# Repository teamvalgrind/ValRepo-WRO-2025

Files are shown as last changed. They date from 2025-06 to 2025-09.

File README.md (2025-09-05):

# Equipo [Team ValGrind]: WRO 2025

(https://postimg.cc/fSTZzy81)

---

## Índice

1. [Nuestro Equipo](#nuestro-equipo)
    - [Integrantes](#integrantes)
    - [Origenes](#origenes)
    - [Nuestro Objetivo](#nuestro-objetivo)
2. [El Robot](#el-robot)
    - [Apartado Mecanico](#apartado-mecanico)
        - [Impresion 3D](#impresion-3d)
        - [Movilidad](#movilidad)
    - [Apartado Electronico](#apartado-electronico)
        - [Sensores](#sensores)
        - [Conexiones y Circuitos](#conexiones-y-circuitos)
        - [Microcontroladores](#microcontroladores)
    - [Apartado Programatico](#apartado-programatico)
        - [Codigo por Componente](#codigo-por-componente)
4. [Recursos para Hacer el Robot](#recursos-para-hacer-el-robot)

---

## Nuestro Equipo

(https://postimg.cc/rKqWdsNG)

Somos **[Team ValGrind]**, entusiastas de la robótica y la innovación. Representamos a nuestra institución en la fase regional de la **WRO 2025**.

---

### Integrantes

- **Samuel Burgos**  
  17 años, 09/01/2008

  > **Rol:** : **Programador**  
> *Especialista en Python y arquitectura de soluciones complejas. Domina GitHub y PyCharm además de algoritmos complejos*.
> **Fun Fact:**  
> *Su banda favorita es Foo Fighters* 

(https://postimg.cc/BLgVJGSN)

- **Sebastián Salina**  
  17 años, 22/08/2008 

  > **Rol:** **Capitán**
> *Diseña piezas en 3D y además posee la capacidad de imprimir estos mismos al manejar una impresora 3D además de ser el mecánico del equipo*  
> **Fun Fact:**  
> *Una vez imprimió un Pokémon gigante de filamento para Cristobal* 

(https://postimg.cc/GH7xXcKJ)

- **Cristobal Mogollón**
   15 años, 14/07/2010
    
   > **Rol:**  **Programador**  
> *Se encarga principalmente de C++, Arduino IDE, y algunos aspectos de la electrónica.*  
> **Fun Fact:**  
> *Una vez le pidió a Sebastián imprimir un Pokémon gigante de filamento*
 (https://postimg.cc/WdfddD3J)

- **Institución:** [Colegio Salto Ángel](https://www.instagram.com/colegiosaltoangel)
- **Instagram Oficial:** [@team_valgrind](https://instagram.com/team_valgrind)
- **Contáctanos:** [valgrind2025@gmail.com](mailto:valgrind2025@gmail.com)
- **Youtube:**
[Team ValGrind](https://youtube.com/@teamvalgrind?si=ZJbz7CX9eOX75H2U)

---

### Origenes

El nombre de nuestro equipo fue decidido por los tres integrantes a partir de un clásico compilador de C++ llamado de la misma forma, el cual es representado por un logotipo de un dragón hecho con origami. El nombre "ValGrind" también hace referencia a la mitología nórdica debido a las legendarias Valquirias que habitan en este.

 (https://postimg.cc/gryddns4)

> ### ¿Por qué nuestro robot se llama Heimdall?

Este nombre no solo es un guiño a la mitología mencionada, sino que además corresponde al dios conocido como el guardián de las puertas de Asgard y del puente Bifröst, que conecta los Nueve Mundos. Al ser un personaje imponente, consideramos que es un nombre apropiado para representar a nuestro robot en la WRO.

## Nuestro Objetivo

(https://postimg.cc/t1LyR68v)

#### "Diseñar, Construir y Programar"
 Un robot autónomo capaz de superar los desafíos de la WRO 2025, utilizando innovación y trabajo en equipo para lograr un desempeño sobresaliente en la etapa regional y avanzar a la nacional. Para llegar a esto, hemos pasado los últimos meses diseñando, construyendo, armando y programando nuestro más nuevo proyecto "Heimdall"

> [!NOTE]
> La World Robot Olympiad (WRO) es una competencia internacional de robótica educativa que se desarrolla en varias fases, y nuestro equipo lógicamente tiene que comenzar por la fase regional, mediante la cual al ganarla se accede a la Fase Nacional. Cada país organiza su propio torneo clasificatorio, donde equipos de jóvenes compiten en distintas categorías, aplicando conocimientos de robótica y STEAM. Por último, la fase a la cual nuestro equipo quiere llegar es la Final Internacional. Los equipos ganadores de cada país participan en la competencia global, donde enfrentan desafíos más complejos y compiten con representantes de más de 95 países 

(https://postimg.cc/yJrQXB1B)

Aún así, nuestro único objetivo no es solamente ganar, como un equipo unido también tenemos la convicción de poder crear un robot no solo funcional, sino que llene nuestras expectativas; A pesar de ser intangible nuestro deseo de poder culminar nuestro proyecto como un equipo unido y verlo brillar, también es una meta importante para nosotros.

---

## El Robot

(https://postimg.cc/Yv33pbFh)

### Apartado Mecanico

| (https://postimg.cc/62RtZ2t4) | (https://postimg.cc/NL6QfHdW)| 
| :--: | :--: |
| *Frontal* | *Posterior* |
|(https://postimg.cc/B8FnTwCv) | (https://postimg.cc/YhtM4CVj)| 
| *Izquierda* | *Derecha* |
|(https://postimg.cc/YLGgYxjf) |(https://postimg.cc/w1fqYYwM) |
| *Superior* | *Inferior* |

#### Impresion 3D 

Antes de hablar de la movilidad o funcionalidad de nuestro robot, primero hay que explicar nuestros métodos de Diseño e Impresión 3D, los cuales se llevaron a cabo mediante Fusion 360

> [!NOTE]
> Fusion 360 es una plataforma de software de modelado 3D, CAD, CAM, CAE y PCB basada en la nube, destinada al diseño y la fabricación de productos. Nos permite diseñar y crear productos de acuerdo a sus especificaciones particulares, garantizando que cada pieza cumpla con los más exigentes criterios de estética, forma, ajuste y funcionalidad. Además, incorpora un conjunto integral de herramientas avanzadas para el diseño de placas de circuito impreso y componentes electrónicos, lo que facilita la conceptualización y materialización de cualquier idea, incluso las más complejas. Al implementar estas funciones, la plataforma optimiza significativamente tanto el tiempo como los costos asociados, asegurando que el proceso de producción se realice de manera eficiente y que las piezas obtenidas sean de la más alta calidad. Nosotros usamos esta herramienta gráfica y de diseño para realizar los diseños del chasis y las piezas personalizadas de nuestro robot.

(https://postimg.cc/G96s8xCh)

#### Movilidad

Ahora bien, ya habiendo dilucidado como podemos elegir, diseñar y imprimir las piezas de nuestro robot, hay que asegurarnos de que este cuente con las herramientas necesarias para moverse y evadir los obstáculos de la pista.

> [!NOTE]
> Video de Heimdall realizando el Open Challenge
[Video](https://youtu.be/av_kJ_hcNXI?si=83bRdQo1FuN1ajur)

> [!NOTE]
> Video de Heimdall esquivando bloques del Closed Challenge 
[Video](https://youtu.be/y2dTKZ1CmCM?si=7QRf_ff8Sa_BZ0Na)

Nuestro robot emplea un sistema de tracción diferencial, ofreciendo maniobrabilidad precisa para enfrentar los retos del campo de competencia. El sistema de cruces se realiza mediante un servo que ajusta la dirección del robot en intersecciones de forma eficaz. También cabe destacar el hecho de que utilizamos una técnica llamada  Ackermann Positivo para emplear el sistema de movilidad de nuestro vehículo.

(https://postimg.cc/30JGfBkv)

##### El diferencial de los vehículos, como su nombre lo indica, permite que exista una diferencia en la velocidad de giro entre la rueda interna y la rueda externa del vehículo cuando se da una vuelta o se está girando la dirección. No importa si el vehículo es tracción trasera o delantera, la función es la misma.

(https://postimg.cc/G4sWpg3Z)

####  Sistema de Movimiento y Tracción 

Ahondando en lo mencionado anteriormente, Heimdall utiliza lo que normalmente es denominado sistema ackermann positivo, el cual es un sistema derivado del principio de Ackermann, cuyo objetivo es lograr que en curvas la **rueda interior (θᵢ) gire más que la exterior (θₒ)** para minimizar deslizamiento lateral (*scrub*).  

- **Ecuación fundamental**:  
  **cot(θₒ) - cot(θᵢ) = W / L**  
  - *W*: Distancia entre pivotes de dirección (batalla)  
  - *L*: Distancia entre ejes  

### **Implementación Física**
```asciidoc
[Rueda exterior (θₒ)]
  │
  ├─── Brazo de dirección  
  │        \  
[Cuadro]──┤         \  
  │        │          \  
  │        │           ●── Centro teórico (eje trasero)  
  │        │          /  
  │        │         /  
  ├─── Brazo de dirección  
  │  
[Rueda interior (θᵢ > θₒ)]
```

---

##### **Relación de Velocidades en Curva**

```
ωₒ / ωᵢ = (R + W/2) / (R - W/2)
```
- `ωₒ`: Velocidad angular rueda exterior.  
- `ωᵢ`: Velocidad angular rueda interior.  
- `R`: Radio de giro del centro del eje.  

---

##### **Fuerzas en Conflicto**

```mermaid
flowchart LR
    A[Motor] --> B[Diferencial]
    B --> C[Semieje der.\nRueda ext. ωₒ]
    B --> D[Semieje izq.\nRueda int. ωᵢ]
    C --> E[Fuerza de tracción ↑]
    D --> F[Ángulo de giro θᵢ > θₒ]
    E & F --> G[Cuadro]
    G --> H{Deflexión estructural?}
    H -->|Sí| I[Pérdida de Ackermann]
    H -->|No| J[Comportamiento ideal]
```

> [!WARNING]
> De utilizar estos sistemas, recomendamos tener cuidado con los siguientes inconvenientes los cuales aparecieron dentro de nuestras prácticas con la implementación del mencionado sistema:

1. **Paradox Steering**:  
   - *Causa*: La tracción en la rueda interior (baja adherencia) contrarresta el ángulo de giro.  
   - *Solución*: Control electrónico (freno vectorial).  

2. **Fatiga en semiejes**:  
   - *Causa*: Torsión excesiva en juntas homocinéticas debido a θᵢ máximo + par motor.  
   - *Solución*: Semiejes asimétricos con ángulos de trabajo optimizados.  

---

##### Soluciones de Ingeniería
-  **Estrategias Recomendadas**

| **Componente** | **Innovación** | **Beneficio** |
|---|---|---|
| **Cuadro** | Subchasis desmontable con rigidez variable. | Permite ajustes finos en competición. |
| **Diferencial**  | Electrónico con mapas por ángulo de giro. | Regula par según θᵢ/θₒ (ej: Honda SH-AWD). |
| **Dirección** | Brazo de Ackermann ajustable (rótulas roscadas). | Compensa desgaste o cambios de neumáticos. |

--- 

(https://postimg.cc/8syssXPz)

El núcleo de la movilidad de nuestro robot reside en su **subsistema mecánico de transmisión y tracción**, cuidadosamente seleccionado con componentes específicos de alta calidad. Vamos a desglosar cómo cada pieza encaja en este rompecabezas de ingeniería en miniatura, usando la escala **1/18** como referencia clave para tamaño e integración:

1.  **Diferenciales y Ejes de Transmisión (1/18)**

(https://postimg.cc/Cz6T56YC)

---

Los diferenciales se ubican en el eje motriz y permiten que las ruedas izquierda y derecha giren a velocidades diferentes al tomar curvas. Esta característica es fundamental para evitar que el robot patine o experimente esfuerzos innecesarios en giros cerrados, manteniendo así la estabilidad incluso durante maniobras agresivas. Su diseño a escala 1/18 asegura que sean compactos, ligeros y proporcionales al resto del chasis y ruedas del robot de competición.

Por otro lado, los ejes de transmisión conectan directamente la salida de los diferenciales (1/18) a las ruedas motrices. Son responsables de transferir el par motor generado hacia las ruedas, permitiendo el giro de los neumáticos. El diseño a escala 1/18 garantiza la longitud y resistencia necesarias para soportar las fuerzas de torsión y tracción, sin añadir peso excesivo ni desbalancear el robot.

En el caso particular del robot Heimdall, originalmente se consideró una transmisión 4x4. Sin embargo, tras observar las limitaciones en los ángulos de cruce y la maniobrabilidad, se optó por priorizar la movilidad. Por ello, se decidió retirar los ejes de transmisión delanteros, transformando el robot en un sistema de tracción 4x2.

---

#### Diferencias mas importantes entre transmisión 4x4 y 4x2 

| Característica | 4x4 (Tracción en las 4 ruedas) | 4x2 (Tracción en 2 ruedas) |
|---|---|---|
| **Motricidad** | Alta, ideal para terrenos irregulares o cruces complejos. | Moderada, suficiente para la mayoría de maniobras en pista controlada. |
| **Ángulo de cruce** | Limitado por la presencia de ejes delanteros. | Mayor libertad de giro y mejor ángulo de cruce. |
| **Estabilidad en curvas** | Más estable en condiciones extremas. | Buena estabilidad, pero depende más del diseño del chasis y el diferencial. |
| **Peso total** | Mayor, por la cantidad extra de componentes (ejes y diferenciales delanteros). | Menor, lo que contribuye a una mejor relación peso-potencia. |
| **Complejidad mecánica** | Más alta; requiere mayor mantenimiento y ajuste. | Más sencilla, facilita el mantenimiento y reduce fallos mecánicos. |
| **Consumo energético** | Más elevado por la transmisión a cuatro ruedas. | Menor, lo que puede aumentar la autonomía. |
| **Aplicación recomendada** | Terrenos difíciles, obstáculos, máxima tracción. | Pistas controladas, mayor maniobrabilidad y agilidad. |

2. **INJORA 7KG 2065 Digital Micro Servo**

El servo INJS2065 es un Servomotor compacto y de alto rendimiento, ideal para aplicaciones de robótica y modelismo a escala. A la hora de tener en cuenta tanto eficiencia como el manejo del espacio en un sistema embebido como el de un robot, el INJS2065 se destaca por sobre otros modelos. así como también destaca por su rápida velocidad de respuesta, alta precisión en el control de ángulo y considerable torque de retención. lo mencionado ut supra le permite operar eficientemente bajo diversas condiciones de carga. Su amplio rango de voltaje de operación, junto con un motor de núcleo y rodamientos de bolas, asegura durabilidad, flexibilidad y un funcionamiento suave, mientras que su tamaño reducido facilita su integración en diseños que requieren soluciones ligeras y confiables.

(https://postimg.cc/bs6kKQT0)

| :wrench: **Especificaciones del Servo INJS2065** | |
|:---|:---:|
| **Banda muerta** | 2 μs |
| **Posición neutral** | 1500 μs / 330 Hz |
| **Tipo de motor** | Motor de núcleo |
| **Ángulo control remoto** | 90-120° ±2° |
| **Ángulo (500-2500 μs)** | 180° ±2° |
| **Rango de voltaje** | 4.8V - 8.4V |
| **Velocidad de operación (6.0V)** | 0.09 s/60° |
| **Velocidad de operación (8.4V)** | 0.06 s/60° |
| **Torque de retención (6.0V)** | 6.0 kg·cm / 83.3 oz·in |
| **Torque de retención (8.4V)** | 7.0 kg·cm / 97.2 oz·in |
| **Dimensiones** | 23 × 13 × 25.8 mm |
| **Peso** | 20 g |
| **Longitud del cable conector** | JR 300 mm |
| **Rodamientos** | 1BB |
| **Peso con empaque** | 28 g |
| **Tamaño del paquete** | 36 × 23 × 38 mm |

---

| :wrench: **Herramientas requeridas** | |
|:---|:---:|
| 1 × Destornillador hexagonal 1.5 mm | |
| 1 × Destornillador hexagonal 2.0 mm | |

3. ### Motor DC 12V Greartisan zga37irg9i

(https://postimg.cc/LY0yTnX2)

Un Motor de Engranajes DC Greartisan es un tipo de motor eléctrico de corriente continua (DC) que tiene una caja de engranajes (también llamada reductora o caja reductora) integrada directamente en su construcción. La principal funcionalidad de este motor en un sistema robótico radica en su capacidad para ofrecer **alto par a velocidades reducidas**. A diferencia de un motor DC estándar que gira a muy altas RPM con poco par, el motor Greartisan integra una **caja de engranajes** (reductora) directamente en su diseño. Esta caja de engranajes transforma la velocidad de rotación del motor en una fuerza mucho mayor.
 El **eje de salida céntrico de 1.45 pulgadas de diámetro** proporciona una conexión robusta y directa a los sistemas mecánicos del robot, como ruedas, brazos articulados o mecanismos de elevación, asegurando que el par generado se transmita de manera eficiente.

> [!TIP]
>  Evita los movimientos bruscos y difíciles de controlar de los motores de alta velocidad sin reducción.
>     Aunque parezca contradictorio, al operar con una relación de engranajes adecuada, el motor puede trabajar más cerca de su punto de eficiencia óptima para la carga que está manejando, lo que puede resultar en un **menor consumo de energía** en comparación con un motor sin engranajes que lucha por alcanzar el par requerido.

### Especificaciones del Motor

| **Característica** | **Valor** |
|---|---|
| **Voltaje nominal** | 12V |
| **Velocidad** | 10 RPM |
| **Material** | Metal |
| **Par nominal** | 33.1 lbs·cm |
| **Relación de reducción interna** | 1:314 |
| **Corriente nominal** | 0.05A |
| **Tamaño del eje de salida (forma D)** | 6 × 14 mm (0.24" × 0.55") (D × L) |
| **Tamaño de la caja de cambios** | 37 × 31 mm (1.46" × 1.22") (D × L) |
| **Tamaño del motor** | 36.2 × 33.3 mm (1.43" × 1.31") (D × L) |

### Cálculo de la reducción total

Para adaptar la salida del motor a las necesidades del robot, realizamos un cálculo de la reducción total combinando la reducción interna del motor con la de un sistema de engranajes externo. Utilizamos un piñón de ataque estándar (acoplado al eje del motor) y engranajes de 17 y 28 dientes.

La relación de reducción adicional por engranajes se calcula así:
- Si el piñón tiene, por ejemplo, 10 dientes, y el engranaje acoplado tiene 28 dientes, la reducción es 28/10 = 2.8.
- Si se agregan más etapas de engranajes (por ejemplo, usando un engranaje intermedio de 17 dientes), la reducción se multiplica por cada etapa.

La reducción total del sistema es:

```
Reducción total = Reducción interna del motor × (dientes engranaje grande / dientes piñón)
```

Con el Piñón de lego de 36 dientes acomplado a nuestro motor, transmitiendo su fuerza de rotación al Piñon de 16 dientes obtenemos un aumento de 2.11 veces la velocidad original del motor (550 rpm) obteniendo así 1164.7 rpm, siendo reducidos por el Piñón de ataque a una reducción de 1:2.24 
Dando un total de 521 rpm las cuales se transmiten directamente a los ejes de transmisión conectados a las ruedas

### ¿Por qué es importante la reducción?

Dos palabras clave: `Velocidad` y `Torque`. Al aumentar la reducción, la velocidad de salida disminuye, permitiendo un control más preciso del robot, y paralelamente  La reducción aumenta el torque disponible en las ruedas, lo que mejora la capacidad de mover el robot o superar obstáculos.

### Razones para elegir este motor y sistema de reducción

- **Versatilidad y control:** El motor de 12V es estándar y confiable. La reducción interna más la reducción por engranajes externos se adapta perfectamente a las necesidades del robot.
- **Adaptabilidad:** Cambiando los engranajes externos se puede ajustar fácilmente la velocidad y el torque final.
- **Eficiencia y disponibilidad:** Los componentes son fáciles de conseguir y económicos.

---

4.  **Tornillos, Tuercas de Seguridad y Arandelas (M2 y M3)**

(https://postimg.cc/cvHx5n1h)

 ##### Ya sean M2 o M3, son piezas imprescindibles para la mecanica de nuestro robot, debido a la fijacion de piezas pequeñas, estabilización de componentes, y la garantía de seguridad que otorgan con respecto al uso prolongado del robot ya sea en practicas o en la competición.
 ##### Se decidió tomar la decisión de tener tornillos M2 y M3 de forma simultánea para velar por la eficiencia del espacio, para permitir compatibilidad con los componentes más pequeños, y al mismo tiempo para garantizar que los tornillos resistan y permitan estabilidad en el robot.
     
---

### Apartado Electronico

Para el proyecto, decidimos usar;

#### **Baterías**

(https://postimg.cc/K3Nx86D1)

##### Diseñadas para potenciar el rendimiento en competiciones de robótica como la WRO, las baterías Tenergy NiMH de 12 V y 2000 mAh ofrecen dos ventajas críticas: su ausencia de efecto memoria garantiza máxima capacidad en cada uso tras recargas frecuentes (ideal para sesiones de prueba extensas), y su formato compacto (1.969x1.142x2.835 pulgadas) con cables desnudos facilita la integración en espacios reducidos de robots. Con carga rápida ≤1A y larga vida útil, son una solución fiable para  cuando necesitemos usarlas por un tiempo prolongado, ya sea en la propia competición o en pruebas.

> [!TIP]
> Para maximizar rendimiento y seguridad en robots**, cargue siempre estas baterías con un cargador compatible NiMH (como el Tenergy 6V-12V) a ≤1A para evitar sobrecalentamiento y prolongar su vida útil (~500 ciclos). Durante competiciones WRO, monitoree la temperatura (detenga si supera 45°C) y verifique el voltaje post-uso (>10.8V ideal); evite descargas profundas (<0.9V/celda) recargando tras 3-4 sesiones. Almacénelas con 40-60% de carga en ambiente fresco (15-25°C), realice mantenimiento cada 4 semanas si no se usan, y en robots proteja el pack contra golpes con aislante anti-vibración. 

| Característica | Detalle |
|---|---|
| Dimensiones del producto | 2,13 x 2,91 x 1,22 pulgadas |
| ASIN | B077Y9HNTF |
| Número de modelo del producto | 19676 |
| Pilas | 10 12V (Tipo de pila necesaria) |
| Opinión media de los clientes | 4.5 de 5 estrellas (748 opiniones) |
| Clasificación en los más vendidos | nº108,878 en Salud y Hogar |
| | nº250 en Pilas 12 V |
| Descatalogado por el fabricante | No |
| Producto en amazon.com desde | marzo 10, 2018 |
| Voltaje | 12 Voltios |
| Reutilización | Recargable |
| Peso de la batería | 225 Gramos |
| Dimensiones del artículo LxWxH | 2,13 x 2,91 x 1,22 pulgadas |
| Peso del artículo | 255 Gramos |
| Amperaje | 1 Amperios |
| UPC | 844949030014 |
| Fabricante | Tenergy |

### **LM2596**

(https://postimg.cc/RJML9J83)

##### El LM2596 es un regulador step down DC-DC diseñado para transformar tensiones elevadas en niveles adecuados para circuitos electrónicos.  Acepta un rango de entrada entre 3.2 y 40V, Lo cual evidentemente demuestra que es un componente electrónico bastante versátil en lo que al manejo de voltaje respecta, por lo tanto nuestro equipo decidió utilizarlo para poder manejar el voltaje en el circuito del robot de forma idónea.

---

### ** Cuadro Resumen del Datasheet**  
| **Parámetro** | **Valor/Descripción** | **Puntos Relevantes** | |
| --- | --- | --- | --- |
| **Rango de entrada** | 3.2–40 V DC | Compatible con baterías LiPo (7.4V), Pb-ácido (12V), o paneles solares. | |
| **Rango de salida** | 1.25–37 V DC ajustable | Ideal para microcontroladores (5V), sensores (3.3V) o motores (6–12V). | |
| **Corriente máxima** | 3 A (pico), 2 A continuo sin disipador | Suficiente para servomotores, drivers de motores, o sistemas de control. | |
| **Eficiencia** | Hasta 92% , ≈73% @3A | Reduce pérdidas térmicas vs. reguladores lineales, crucial en sesiones largas. | |
| **Frecuencia** | 150 kHz | Permite usar componentes magnéticos pequeños (compacto). | |
| **Temperatura operativa** | -40°C a +85°C | Funciona en entornos extremos (competiciones exteriores). | |
| **Dimensiones** | 45×20×14 mm (estándar) | Fácil integración en espacios reducidos de robots. | |
| **Protecciones** | Limitación de corriente | Previene daños por cortocircuitos en cables o motores. | |
| | | | |

---

### Funcionamiento Técnico 
El LM2596 sigue una topología **buck clásica** con cuatro componentes clave:  
1. **Interruptor (MOSFET)**: Regula el flujo de energía mediante PWM a 150 kHz .  
2. **Bobina (inductor)**: Almacena energía magnética durante el ciclo "ON" y la libera en el "OFF", estabilizando el voltaje .  
3. **Diodo**: Cierra el circuito durante la fase de descarga de la bobina .  
4. **Capacitor**: Filtra rizados (<50 mV ), crucial para microcontroladores sensibles al ruido.  

> [!TIP]
>     - Usar disipador si la corriente supera 1.5A .  
>  - Monitorear temperatura con termómetro IR (>45°C indica riesgo) .  
  - Mantener diferencia mínima de **1.5V entre entrada/salida** (ej: 7.4V entrada → 5V salida) .  
  - Para motores, agregar un **fusible de 2–3A** en serie .    
  - Usar cables AWG 18+ para corrientes >2A .  
  - Evitar loops largos en entrada/salida para reducir rizado.  

---

#### Driver L298N

(https://postimg.cc/Jy29P1P3)

Es un **controlador de motores de doble puente H (dual H-bridge)** encapsulado en un circuito integrado. Su función principal es actuar como un "intermediario de potencia" entre dispositivos de control de baja potencia (como Arduino) y motores de alta potencia (como tu motor DC 12V).

**Es extremadamente útil para nuestro proyecto debido a su:**

1. **Amplificación de corriente:**  
   - Los microcontroladores solo pueden entregar ~20-40mA por pin.  
   - El L298N soporta hasta **2A por canal** (suficiente para motores medianos).  
2. **Control direccional:**  
   - Permite invertir la polaridad del voltaje aplicado al motor para cambiar su giro (adelante/atrás).  
3. **Protección eléctrica:**  
   - Aísla el circuito de control de los picos de voltaje generados por el motor.  
4. **Manejo de alta tensión:**  
   - Soporta motores de 5V a 35V (ideal para tu motor 12V).  

---

#### **Partes clave del módulo L298N:**  
| **Componente** | **Función** |
|---|---|
| **Puertos de salida** (OUT1, OUT2, OUT3, OUT4) | Conectan los motores (2 motores DC o 1 motor paso a paso). |
| **Entradas lógicas** (IN1, IN2, IN3, IN4) | Reciben señales de control desde Arduino (determinan dirección). |
| **Pines de habilitación** (ENA, ENB) | Activan/desactivan los canales (con/sin PWM). |
| **Regulador de 5V** | Provee energía a la lógica (puede alimentar al Arduino si se usa el jumper).|
| **Disipador de calor** | Metálico, previene sobrecalentamiento durante uso prolongado. |
| **Jumpers** | Configuran el modo de operación (ej: habilitación permanente de canales). |

---

#### **¿Cómo controla un motor DC?**  
Usa un circuito **puente H (H-bridge)** interno:  
``` 
   [IN1] --[SW1]---- Motor ----[SW3]-- [IN2]  
               |                   |  
              [SW2]               [SW4]  
```  
- **Giro adelante:**  
  `IN1 = HIGH` (SW1 cerrado) + `IN2 = LOW` (SW4 cerrado) → Corriente fluye: SW1 → Motor → SW4  
- **Giro atrás:**  
  `IN1 = LOW` (SW2 cerrado) + `IN2 = HIGH` (SW3 cerrado) → Corriente fluye: SW3 → Motor → SW2  
- **Frenado:**  
  `IN1 = HIGH` + `IN2 = HIGH` → Cortocircuito en bornes del motor (frena rápidamente).  

---

#### Sensores Ultrasónicos 

(https://postimg.cc/N94J25h9)

##### El robot cuenta con múltiples sensores ultrasónicos (HC-SR04) ubicados estratégicamente para la detección de obstáculos y el cálculo de distancias, permitiendo navegación autónoma y segura. El sensor HC-SR04 es un sensor de distancia de bajo costo, por lo que su uso es muy frecuente en la robótica. Incorpora un par de transductores de ultrasonido que se utilizan de manera conjunta para determinar la distancia del sensor con un objeto colocado frente a este. Un transductor emite una ráfaga de ultrasonido y el otro capta el rebote de dicha onda.

> [!NOTE]
> El tiempo que tarda la onda sonora en ir y regresar a un objeto puede utilizarse para conocer la distancia entre el origen del sonido y el objeto. La interfaz del sensor HC-SR04 y Arduino se logra mediante 2 pines digitales: el pin de disparo (trigger) y el pin de eco (echo). La función de cada uno de estos pines es la siguiente:
- El pin trigger recibe un pulso de habilitación del microcontrolador, mediante el cual se le indica al módulo que comience a realizar la medición de distancia.
- En el pin echo el sensor devuelve al microcontrolador un pulso cuyo ancho es proporcional al tiempo que tarda el sonido en viajar del transductor al obstáculo y luego de vuelta al módulo

- ### ** Cuadro Técnico**  

| **Parámetro** | **HC-SR04** (Estándar) | **US-100** (Avanzado) | **Importancia en Robótica** |
|---|---|---|---|
| **Voltaje operación** | 5 V DC | 2.4–5.5 V DC | Compatibilidad con microcontroladores (3.3V/5V). |
| **Consumo (standby)** | 2 mA | 2 mA | Eficiencia energética en robots autónomos. |
| **Rango de detección** | 2 cm – 400 cm | 2 cm – 450 cm | Evitar colisiones (obstáculos cercanos/lejanos). |
| **Resolución** | 0.3 cm | 0.1 cm | Precisión en navegación de precisión (ej: laberintos). |
| **Ángulo del haz** | 15° | 15° (ajustable a 5° con tubo)| Enfoque en objetivos específicos, reduce falsos positivos. |
| **Frecuencia operativa** | 40 kHz | 42 kHz | Minimiza interferencias con otros sensores acústicos. |
| **Tiempo respuesta** | ≤ 50 ms | ≤ 30 ms | Reacción rápida en robots de alta velocidad (ej: FRC). |
| **Interfaz de salida** | Digital (pulso) | UART/TTL o Digital | Flexibilidad para Arduino, Raspberry Pi, o SBCs. |
| **Precisión** | ±3 mm (2–100 cm), ±5% (>100 cm) | ±2 mm (2–300 cm) | Crítico para mapeo de entornos (SLAM). |
| **Temperatura operativa** | -15°C a +70°C | -25°C a +85°C | Funcionamiento en entornos extremos (exteriores/industriales). |
| **Compensación térmica** | No | Sí (sensor interno) | Mediciones estables con cambios de temperatura. |
| **Dimensiones** | 45×20×15 mm | 41×21×16 mm | Integración en espacios reducidos (mini-robots, drones). |

#### Pixy2

(https://postimg.cc/p9wVTN3Z)

La **Pixy2** es una cámara de visión artificial diseñada para robots que requieren detección rápida y fiable de objetos, colores y códigos de barras. Junto con su software **PixyMon**, forma un ecosistema accesible para principiantes y avanzados, ideal para la detección de los bloques del desafío cerrado. A diferencia de soluciones basadas en cámaras genéricas, Pixy2 procesa imágenes *onboard* con algoritmos optimizados, liberando al microcontrolador principal (Arduino, Raspberry Pi) de tareas intensivas. Su enfoque en **"aprender por demostración"** simplifica el entrenamiento sin necesidad de programación compleja.

---

### ** Cuadro de Datos Técnicos Clave**  
| **Parámetro** | **Pixy2 CMUcam5** | **Puntos Relevantes** | |
| --- | --- | --- | --- |
| **Sensor** | Sony IMX322 (1/4") | Captura 60 FPS en baja luz (torneos indoor/outdoor). | |
| **Resolución** | 1296×976 (RAW), 400×296 (procesada) | Balance óptimo entre detección y velocidad. | |
| **Detección** | Colores (7 firmas), Líneas, Códigos QR, Objetos | Ideal para seguimiento de trayectorias, identificación de objetivos. | |
| **Interfaces** | UART, SPI, I²C, USB, GPIO | Conexión directa a Arduino, Raspberry Pi, PLCs. | |
| **Latencia** | <3 ms (por objeto) | Respuesta en tiempo real para robots ágiles. | |
| **Consumo** | 140 mA @ 5V (máx.) | Alimentable desde puerto USB o fuente de robot. | |
| **Algoritmos integrados** | RANSAC, Vectorización | Detección precisa de líneas incluso con curvas o rupturas. | |
| **Dimensiones/Weight** | 40×40×13 mm / 26 g | Montaje en drones o mini-robots sin afectar movilidad. | |

---

###  Configuración para Entrenamiento de Detección de Colores

(https://postimg.cc/mPBmLMfz) 

1. **Preparación del entorno**:  
   - Iluminar el objeto uniformemente (evite sombras/reflejos).  
   - Usar fondos contrastados (ej: objeto rojo sobre fondo blanco).  

2. **Captura de firmas (signatures)**:  
   - Conecte Pixy2 vía USB y abrir PixyMon → Menú `Action` → `Set signature...`.  
   - Presione el botón físico en Pixy2 o haga clic en `Detect objects` para capturar el color.  
   - Ajuste la sensibilidad con el deslizador `Saturation` (alto para colores vivos, bajo para pasteles).  

3. **Afinación avanzada**:  
   - En `Expert mode`, defina rangos HSV (`Hue`, `Saturation`, `Value`) para reducir falsos positivos.  
   - Use `Color codes` para crear códigos de barras con 2-3 colores (ej: logotipo de competencia WRO).  

4. **Pruebas en tiempo real**:  
   - Active `Frame view` en PixyMon para ver detecciones superpuestas (objetos = rectángulos, líneas = vectores).  
   - Ajuste `Min/max area` para filtrar objetos por tamaño (evitar ruido).   

#### Diagramas de Flujo

##### En este diagrama de flujo se halla una representación gráfica del funcionamiento lógico de nuestra programación, así como de lo que se espera sea el desempeño del robot al inicializar el programa.

##### Desafío Abierto

```mermaid
flowchart LR
    A[Inicio] --> B[Esperar botón de inicio]
    B -- Botón presionado --> C[Iniciar programa]
    C --> D[Contador de giros < 12?]
    D -- No --> E[Avanzar 1.5s y detenerse]
    E --> F[Fin]
    D -- Sí --> G[Leer sensores ultrasónicos]
    G --> H{¿Frontal > 20cm?}
    H -- Sí --> I[Avanzar recto]
    I --> J{¿En tiempo de espera tras giro?}
    J -- Sí --> G
    J -- No --> K{¿Izquierda > 200cm?}
    K -- Sí --> L[Girar izquierda, +1 giro, reset tiempo]
    L --> I
    K -- No --> M{¿Derecha > 200cm?}
    M -- Sí --> N[Girar derecha, +1 giro, reset tiempo]
    N --> I
    M -- No --> I
```

##### Desafío Cerrado

```mermaid
flowchart LR
    A([Inicio]) --> B([void setup])
    B --> C{¿Botón presionado?}
    C -- No --> C
    C -- Sí --> D([programaIniciado = true])
    D --> E([void loop])
    E --> F{¿finalizado?}
    F -- Sí --> G([Termina])
    F -- No --> H([doceGiros])
    H --> I[Lectura sensores]
    I --> J{¿Pixy2 detecta bloques?}
    J -- Sí --> K([goToPosition])
    J -- No --> L{¿Obstáculo al frente?}
    L -- No --> M{¿Espacio libre?}
    M -- Sí --> N[Girar o avanzar]
    M -- No --> O[Parar]
    L -- Sí --> O
    K --> G
    N --> G
    O --> G
```

#### Diagrama de Conexiones 

#### Microcontroladores

##### ESP-32

(https://postimg.cc/f3gkzvyJ)

##### El **ESP32-WROOM** es un módulo todo-en-uno potente y económico basado en el chip ESP32, que integra un **procesador dual-core de hasta 240 MHz**, **Wi-Fi 802.11 b/g/n (2.4 GHz)**, y **Bluetooth (Clásico y BLE)**, junto con **4 MB de memoria flash SPI y 520 KB de RAM** en el mismo encapsulado, además de una antena PCB integrada; ofrece múltiples periféricos (GPIOs, ADC, DAC, UART, SPI, I2C, PWM, etc.), soporta modos de bajo consumo para baterías, y es ideal para proyectos de IoT, domótica, robótica o interfaces, siendo fácil de programar con Arduino IDE, ESP-IDF o MicroPython.
##### Además del microcontrolador, también es necesario tener un buen entorno con las librerías necesarias para compilar y interpretar el código, y eventualmente crear un ecosistema óptimo para nuestro robot. Por esto, hemos decidido utilizar 4 librerías esenciales para lograr nuestro objetivo:

1.  **`Wire.h` (Comunicación I²C):**  
    Esencial para conectar sensores, pantallas (OLED) o memorias (EEPROM) que usen el bus I²C. Con `Wire.begin(SDA, SCL)` configuras los pines, luego usas `Wire.beginTransmission()`, `Wire.write()`, `Wire.read()` y `Wire.endTransmission()` para enviar/recibir datos. A partir de esta librería establecemos comunicación con el ESP-32.

2.  **`NewPing` (Sensor de Distancia Ultrasónico):**
La librería NewPing simplifica y optimiza el uso de sensores ultrasónicos como el HC-SR04. Se inicializa con NewPing sonar(TRIG, ECHO, MAX_DISTANCE), y métodos como sonar.ping_cm() devuelven la distancia en centímetros de forma rápida y precisa. Es ideal para proyectos que requieren detección de proximidad sin contacto, como evitar obstáculos en pistas, prevenir colisiones con paredes internas o externas, sistemas de estacionamiento, y robótica móvil. NewPing maneja automáticamente la generación y recepción de pulsos ultrasónicos, mejora la velocidad de medición y reduce errores gracias a funciones avanzadas como mediciones medianas y control de tiempo máximo de eco.

3.  **`ESP32Servo.h` (Control de Servomotores):**  
    Librería específica para manejar servos en el ESP32, ya que los timers PWM son distintos a Arduino. Con `servo.attach(PIN)` configuras y `servo.write(grados)` posicionas el servo (0°-180°). Crucial para manejar automatismos y conseguir movimiento angular preciso con motores de bajo torque.

4.  **`PixySPI2.h` (Cámara Inteligente Pixy2):**  
    Facilita la comunicación con la cámara Pixy2 (vía SPI) para visión artificial simple. Detecta objetos por color, formas (bloques) o líneas. Usas `pixy.init()` y `pixy.ccc.getBlocks()` para obtener datos. A partir de la pixy, podemos crear código que pueda identificar los bloques verdes, rojos, y el estacionamiento magenta para que actúe acorde y pueda realizar el desafío cerrado.

5 **`SPI.h` (Comunicación SPI en Arduino):**
    La librería SPI.h facilita la comunicación rápida y síncrona entre Arduino (como maestro) y dispositivos periféricos mediante el protocolo Serial Peripheral Interface (SPI). Se inicializa con SPI.begin(), y permite enviar y recibir datos simultáneamente con SPI.transfer(). Es ideal para conectar sensores, memorias, pantallas, y otros módulos que requieren alta velocidad y comunicación full-duplex en distancias cortas. SPI maneja automáticamente las señales de reloj, selección de esclavos (SS), y líneas de datos (MOSI y MISO), simplificando la gestión del bus. Además, ofrece funciones para configurar la velocidad, orden de bits y modo de reloj, adaptándose a distintos dispositivos y aplicaciones industriales o robóticas.

### ¿Por qué Pixy2SPI.h?

 La decisión entre usar **`Pixy2SPI.h`** (comunicación SPI) o **`Pixy2.h`** (comunicación I2C) fue un problema con el que nos encontramos apenas comenzamos a utilizar la PixyCam™. En nuestra experiencia, podemos declarar que el protocolo de comunicación SPI transmite datos de forma más rápida que mediante I²C, y por tanto creemos que vale la pena el elegir Pixy2SPI para poder recibir `signatures`
y datos apenas la pixy los procese

### **1. Rendimiento y Velocidad**  
- **`Pixy2SPI.h` (SPI)**:  
  - **Velocidad máxima**: Hasta **10 Mbps** (dependiendo del microcontrolador).  
  - **Ventaja**: Ideal para aplicaciones que requieren **alta velocidad** (ej: robots en competiciones, procesamiento en tiempo real).  
  - SPI es **full-duplex**, permitiendo transmisión y recepción simultáneas.  

- **`Pixy2.h` (I2C)**:  
  - **Velocidad máxima**: Típicamente **400 kHz** (modo estándar) o **1 MHz** (modo rápido).  
  - **Limitación**: Puede causar cuellos de botella si se transfieren muchos bloques/objetos por fotograma.  

> [!WARNING] 
> ☑️ **Elige SPI si:** Necesitas máxima velocidad (ej: seguimiento de objetos rápidos, FPS alto).
> 
> ☑️**Elige SPI si:** Trabajas en entornos eléctricamente ruidosos (un robot de la WRO)

---

#### Otras razones por las cuales el protocolo SPI nos resultó favorable en testeo y ejecución de la PixyCam en pista:

##### **SPI**:  
  - **Menos susceptible a ruido** gracias a señales de reloj dedicadas y conexiones punto a punto.  
  - Ideal para entornos con motores o fuentes de interferencia (ej: competiciones **FIRST Robotics**).  

##### **I2C**:  
  - Más sensible al ruido debido a su diseño multi-dispositivo en 2 cables.  
  - Puede requerir pull-up resistors adicionales para evitar fallos.  

---

### Apartado Programático

#### Código por Componente

##### Desafío Abierto

El código desarrollado para el robot Heimdall en la categoría Futuros Ingenieros de la WRO 2025 está estructurado para automatizar las acciones del robot en la pista, desde la inicialización hasta la finalización de su recorrido. 

 A continuación, se describe a lujo de detalle y con ejemplos de código cada parte fundamental de este sistema.

Para empezar, se definen los pines y las constantes necesarias para la operación del hardware. Los sensores ultrasónicos se conectan a diferentes pines del ESP32, y se prepara el control del motor y del servo. También se establecen los umbrales de distancia y tiempos que serán usados para la lógica de navegación.

```cpp
#define USTFRONT 13
#define USEFRONT 12
#define USTLEFT 14
#define USELEFT 27
#define USTRIGHT 26
#define USERIGHT 25

#define MAX_DISTANCE 357
#define IN2 17
#define IN1 16
#define PIN_SERVO 2
#define PIN_BOTON 4

const int DISTANCIA_OBSTACULO_FRONTAL = 20;
const int DISTANCIA_OBSTACULO_LATERAL = 200;
const unsigned long DURACION_GIRO_I = 460;
const unsigned long DURACION_GIRO_D = 390;
const unsigned long TIEMPO_ESPERA_GIRO = 1000;
```

El sistema utiliza librerías como `NewPing` para manejar los sensores ultrasónicos y `ESP32Servo` para el control del servo. La inicialización de estos dispositivos es esencial para que el robot tenga control de su entorno y de su propio movimiento:

```cpp
#include <Wire.h>
#include <NewPing.h>
#include <ESP32Servo.h>

NewPing USFRONT(USTFRONT, USEFRONT, MAX_DISTANCE);
NewPing USLEFT(USTLEFT, USELEFT, MAX_DISTANCE);
NewPing USRIGHT(USTRIGHT, USERIGHT, MAX_DISTANCE);

Servo myservo;
```

Las variables de control permiten al robot llevar registro de su estado, los giros realizados y el tiempo entre cada giro, para evitar movimientos no deseados o repetitivos. Estas variables se usan a lo largo del flujo principal del programa.

```cpp
bool programaIniciado = false;
bool finalizado = false;

unsigned long tiempoUltimoGiro = 0;
int contadorGiros = 0;
```

La función `setup()` es la encargada de preparar todo el hardware. Aquí se asocia el servo, se configura la comunicación serial para mensajes de depuración y se definen los pines como entradas o salidas según su función. El servo se centra y todo el sistema espera la interacción del usuario antes de iniciar la lógica automática.

```cpp
void setup() {
  myservo.attach(PIN_SERVO);
  Serial.begin(115200);

  pinMode(PIN_BOTON, INPUT_PULLUP);
  pinMode(IN1, OUTPUT);
  pinMode(IN2, OUTPUT);

  digitalWrite(IN1, LOW);
  digitalWrite(IN2, LOW);
  myservo.write(99);  // Servo centrado
  delay(3000);

  Serial.println("Esperando pulsar botón para iniciar...");
}
```

El ciclo principal del programa se encuentra en `loop()`, donde el robot permanece a la espera de que el usuario pulse el botón de inicio. Una vez detectada la pulsación, el programa entra en la rutina de navegación y ya no responde a más pulsaciones hasta que termina la secuencia de giros.

```cpp
void loop() {
  if (!programaIniciado) {
    if (digitalRead(PIN_BOTON) == LOW) {
      programaIniciado = true;
      Serial.println("Botón presionado, iniciando programa...");
      delay(500);  // debounce
    }
  } else if (!finalizado) {
    docegiros();
  }
}
```

La función `docegiros()` es la función principal dentro del código. Aquí se leen los sensores ultrasónicos, se decide si avanzar o girar, y se lleva el conteo de los giros. Un ejemplo de lectura de los sensores y validación de las lecturas sería:

```cpp
void docegiros() {
  unsigned long ahora = millis();

  int frontal = USFRONT.ping_cm();
  int izquierda = USLEFT.ping_cm();
  int derecha = USRIGHT.ping_cm();

  if (frontal == 357) frontal = -1;
  if (izquierda == 357) izquierda = -1;
  if (derecha == 357) derecha = -1;

  Serial.print("Distancias (cm) - Frontal: ");
  Serial.print(frontal);
  Serial.print(" | Izquierda: ");
  Serial.print(izquierda);
  Serial.print(" | Derecha: ");
  Serial.println(derecha);

  if (contadorGiros >= 12) {
    if (!finalizado) {
      Serial.println("Se alcanzaron 12 giros, avanzando 1 segundo más y deteniéndose.");
      Adelante();
      delay(700);
      Parar();
      finalizado = true;
    }
    return;
  }

  if (frontal != -1 && frontal > DISTANCIA_OBSTACULO_FRONTAL) {
    Adelante();
  }

  if (ahora - tiempoUltimoGiro < TIEMPO_ESPERA_GIRO) {
    Serial.println("Avanzando recto después del giro, sin girar");
  } else {
    if (izquierda != -1 && izquierda > DISTANCIA_OBSTACULO_LATERAL) {
      Serial.println("Girando a la izquierda por más de 190 cm libres");
      Izquierda();
      contadorGiros++;
      tiempoUltimoGiro = millis();
      Adelante();
    } else if (derecha != -1 && derecha > DISTANCIA_OBSTACULO_LATERAL) {
      Serial.println("Girando a la derecha por más de 190 cm libres");
      Derecha();
      contadorGiros++;
      tiempoUltimoGiro = millis();
      Adelante();
    }
  }
}
```

Las funciones auxiliares de movimiento encapsulan la lógica para avanzar, parar y girar. Por ejemplo, para avanzar el motor se activa y para parar se desactiva:

```cpp
void Adelante() {
  digitalWrite(IN1, HIGH);
  Serial.println("Motor en marcha hacia adelante");
}

void Parar() {
  digitalWrite(IN1, LOW);
  Serial.println("Motor detenido");
}
```

Los giros a izquierda y derecha combinan el movimiento del motor con el ajuste del servo, utilizando temporizadores para asegurar que el giro tenga la duración adecuada. Así, el robot puede girar de manera controlada y precisa antes de volver a avanzar.

```cpp
void Izquierda() {
  digitalWrite(IN1, HIGH);
  myservo.write(150);
  unsigned long inicio = millis();
  while (millis() - inicio < DURACION_GIRO_I) {
    delay(10);
  }
  myservo.write(97);  // Centrar servo
  digitalWrite(IN1, LOW);
  Serial.println("Giro izquierda completado");
}

void Derecha() {
  digitalWrite(IN1, HIGH);
  myservo.write(30);
  unsigned long inicio = millis();
  while (millis() - inicio < DURACION_GIRO_D) {
    delay(10);
  }
  myservo.write(100);  // Centrar servo
  digitalWrite(IN1, LOW);
  Serial.println("Giro derecha completado");
}
```

En resumen, este sistema permite que el robot navegue autónomamente por la pista, tome decisiones en tiempo real basadas en la información de los sensores, y complete el reto de realizar 12 giros antes de detenerse automáticamente. Se decidió usar funciones auxiliares para poder crear un "ecosistema" de herramientas que nos permitieran manejar el comportamiento y preferencias del robot de tal forma que su desempeño en la pista sea fácilmente optimizable. Esto también ocurre dentro del Desafío Cerrado

##### Desafío Cerrado

La lógica de programación del Desafío Cerrado se basa principalmente en la integración y procesamiento de la información proporcionada por la cámara Pixy2, junto con la interpretación de datos de sensores ultrasónicos y la reacción coordinada de los motores y el servo de dirección. El objetivo es que el robot detecte colores específicos en la pista (por ejemplo, bloques verdes o rojos), interprete su posición y tome decisiones inteligentes y adaptativas para sortear obstáculos o ejecutar maniobras según el contexto de la competencia.

Para lograr esto, el sistema parte de una inicialización robusta de todos los periféricos. Se definen los pines y canales de control para el motor (mediante un puente H y PWM), el servo de dirección, el botón de inicio y los sensores ultrasónicos distribuidos en el frente y laterales del robot. También se configura la cámara Pixy2 para operar en modo de detección de componentes de color, lo que facilita la identificación rápida y eficiente de objetos de interés en la pista. Un fragmento típico de esta inicialización se ve así:

```cpp
#include <Wire.h>
#include <ESP32Servo.h>
#include <SPI.h>
#include <Pixy2SPI_SS.h>
#include <NewPing.h>

#define IN1 16
#define IN2 17
#define MOTOR_PWM_CHANNEL 6
#define MOTOR_PWM_PIN IN1
#define PIN_SERVO 2
#define PIN_BOTON 4

#define USTLEFT 14
#define USELEFT 27
#define USTRIGHT 26
#define USERIGHT 25
#define USTFRONT 13
#define USEFRONT 12

Pixy2SPI_SS pixy;
Servo myservo;

NewPing sensorFront(USTFRONT, USEFRONT, 357);
NewPing sensorIzq(USTLEFT, USELEFT, 357);
NewPing sensorDer(USTRIGHT, USERIGHT, 357);
```

Desde el arranque, el robot permanece en estado de espera hasta que el usuario presiona el botón de inicio. En ese momento, se inicia la secuencia de centrado y avance, y el robot comienza a monitorear constantemente la información visual y de proximidad. Mediante la función `loop`, el robot evalúa el estado general y ejecuta acciones basadas en una máquina de estados que contempla escenarios como avanzar, girar, retroceder ante obstáculos, realizar correcciones de trayectoria y ejecutar maniobras especiales ante la detección de colores específicos:

```cpp
void loop() {
  if (!programaIniciado) {
    if (digitalRead(PIN_BOTON) == LOW) {
      programaIniciado = true;
      Serial.println("Programa iniciado.");
      delay(500);
      estadoActual = CENTRANDO_INICIAL;
      tiempoInicio = millis();
    }
    return;
  }

  pixy.ccc.getBlocks();

  int front = leerSensorFiltrado(sensorFront);
  int left = leerSensorFiltrado(sensorIzq);
  int right = leerSensorFiltrado(sensorDer);

  switch (estadoActual) {
    case ESPERANDO:
      break;
    case CENTRANDO_INICIAL:
      estadoActual = AVANZANDO;
      break;
    case AVANZANDO:
      // ... lógica de avance y detección de obstáculos
      break;
    // ... otros estados
  }
}
```

Parte esencial de la lógica es el procesamiento de los bloques detectados por la Pixy2. En cada ciclo, se consulta la cantidad de bloques detectados. Si hay bloques, se leen sus coordenadas y su firma (color). Esta información se utiliza para determinar acciones específicas. Por ejemplo, si se detecta un bloque verde (firma 1) y este está en una posición determinada del encuadre de la cámara, el robot puede decidir avanzar recto o realizar un giro suave a la izquierda. En caso contrario, si no hay bloques o la posición no coincide con los umbrales establecidos, el robot puede corregir su trayectoria o seguir avanzando recto, manteniendo siempre la lógica adaptativa.

```cpp
pixy.ccc.getBlocks();

if (pixy.ccc.numBlocks) {
  int y = pixy.ccc.blocks[0].m_y;
  int x = pixy.ccc.blocks[0].m_x;
  uint8_t sig = pixy.ccc.blocks[0].m_signature;

  Serial.print("Firma detectada: ");
  Serial.println(sig);
  Serial.print("Posición X: ");
  Serial.print(x);
  Serial.print(" Y: ");
  Serial.println(y);

  if (sig == 1 && y > UMBRAL_Y) {
    if (!girando) {
      girando = true;
      tiempoInicioGiro = millis();

      if (x > UMBRAL_IZQUIERDA) {
        Serial.println("Bloque verde a la derecha: Avanzar recto");
        Adelante();
        giroIzqActivo = false;
      } else {
        Serial.println("Bloque verde a la izquierda: Giro suave izquierda");
        giroIzquierdaSuave();
        giroIzqActivo = true;
      }
    } else {
      Adelante();
    }
  } else {
    if (girando && millis() - tiempoInicioGiro >= TIEMPO_GIRO_SUAVE) {
      if (giroIzqActivo) {
        Serial.println("Corrección giro derecha para enderezar");
        correccionDerecha();
      }
      girando = false;
    } else {
      Adelante();
    }
  }
} else {
  if (girando && millis() - tiempoInicioGiro >= TIEMPO_GIRO_SUAVE) {
    if (giroIzqActivo) {
      Serial.println("Corrección giro derecha para enderezar");
      correccionDerecha();
    }
    girando = false;
  } else {
    Adelante();
  }
}
```

Las funciones de control de movimiento se encargan de traducir las decisiones de la lógica central en acciones físicas del robot. Por ejemplo, la función `Adelante` activa el motor para avanzar recto y centra el servo; `giroIzquierdaSuave` ajusta el servo para un giro controlado a la izquierda; y `correccionDerecha` realiza una corrección puntual al servo para volver a la trayectoria central tras un giro.

```cpp
void Adelante() {
  digitalWrite(IN1, HIGH);
  digitalWrite(IN2, LOW);
  myservo.write(97);
  Serial.println("Avanzando recto");
}

void giroIzquierdaSuave() {
  digitalWrite(IN1, HIGH);
  digitalWrite(IN2, LOW);
  myservo.write(140);
  Serial.println("Girando suavemente a la izquierda");
}

void correccionDerecha() {
  digitalWrite(IN1, HIGH);
  digitalWrite(IN2, LOW);
  myservo.write(30);
  delay(TIEMPO_CORRECCION);
  myservo.write(97);
  Serial.println("Corrección giro derecha completada");
}
```

La integración de los sensores ultrasónicos permite al robot complementar la información visual de la Pixy2 con la percepción de distancias a los obstáculos. Así, el robot no solo reacciona a los colores detectados, sino que también puede evitar colisiones y ajustar su trayectoria para sortear paredes o bloques inesperados. Para este fin, la lectura de los sensores se filtra y se promedia para reducir el efecto del ruido y obtener medidas más confiables:

```cpp
int leerSensorFiltrado(NewPing& sensor) {
  int lecturas[LECTURAS_SENSOR];
  for (int i = 0; i < LECTURAS_SENSOR; i++) {
    lecturas[i] = sensor.ping_cm();
    delay(10);
  }
  // Ordenar lecturas (bubble sort simple)
  for (int i = 0; i < LECTURAS_SENSOR - 1; i++) {
    for (int j = 0; j < LECTURAS_SENSOR - i - 1; j++) {
      if (lecturas[j] > lecturas[j + 1]) {
        int temp = lecturas[j];
        lecturas[j] = lecturas[j + 1];
        lecturas[j + 1] = temp;
      }
    }
  }
  // Usar la mediana
  return lecturas[LECTURAS_SENSOR / 2];
}
```

El uso de una **máquina de estados** permite que el robot maneje situaciones complejas, como la secuencia de retroceder y girar en caso de encontrar un obstáculo frontal, o la lógica de doble giro y corrección tras superar cruces especiales. Cada estado define no solo qué hacer en cada momento, sino también cuándo y cómo pasar al siguiente estado, dependiendo de los tiempos, las lecturas de sensores y las señales de la Pixy2. Por ejemplo, tras detectar un obstáculo, el robot puede retroceder, ejecutar un giro, y luego avanzar sin corrección durante un tiempo predefinido antes de volver al modo de navegación normal.

La función encargada de decidir la reacción ante un bloque detectado por la Pixy2 evalúa tanto el color como la posición X para determinar si se debe iniciar un giro parcial o completo, y en qué dirección:

```cpp
void detectarBloque(uint8_t color, int x) {
  if (color == 1) { // Verde
    if (x >= UMBRAL_IZQUIERDA && x <= UMBRAL_DERECHA) {
      iniciarGiroParcial(1);
    } else if (x < UMBRAL_IZQUIERDA) {
      iniciarGiro(1);
    }
  } else if (color == 2) { // Rojo
    if (x >= UMBRAL_IZQUIERDA && x <= UMBRAL_DERECHA) {
      iniciarGiroParcial(2);
    } else if (x > UMBRAL_DERECHA) {
      iniciarGiro(2);
    }
  }
}
```

---

Dentro de `Desafio-abierto.ino` y `Desafio-cerrado.ino` está el resto de funciones descritas, y la lógica de programación mediante la cual el robot completa el desafío abierto y cerrado.

#### Compiladores y Comunicacion

- **Lenguaje principal:** C++ (Arduino IDE)
- **Compilador:** [Arduino IDE](https://www.arduino.cc/en/software- **Comunicación entre módulos:** Bus I2C

---

## Recursos para Hacer el Robot

| Producto | Cantidad | Precio | Tipo | Link |
|---|---|---|---|---|
| Tenergy TB-6AB Balance Charger Discharger 1S-6S | 1 | 39.99$ | Electrónico | [Enlace](https://a.co/d/g4CIJV4) |
| Tenergy 2 Pack 12V 2000mAh Battery Packs RC | 1 | 39.99$ | Electrónico | [Enlace](https://a.co/d/7CcqbaV) |
| 1683 Pcs M3 Screw Assortment | 2 | 16.99$ | Herramienta | [Enlace](https://a.co/d/hlXXkAq) |
| Vertical Heat Press Machine-Heat Set Insert Tool | 1 | 56.99$ | Herramienta | [Enlace](https://a.co/d/0QgemD) |
| FNIRSI HS-02A 100W Portable Corded Soldering Iron Kit | 1 | 95.99$ | Herramienta | [Enlace](https://a.co/d/7zn4xyp) |
| Kit de amortiguación y dirección escala 1/24 | 1 | 33$ | Herramienta | [Enlace](https://a.co/d/1lKXhpT) |
| Caja de engranajes diferenciales escala 1/28 | 1 | 14$ | Herramienta | [Enlace](https://a.co/d/7Y6jsIC) |
| Diferenciales y ejes de transmisión 1/28 | 1 | 27$ | Mecánico | [Enlace](https://a.co/d/1KSovrP) |
| Conectores XT30 | 1 | 13$ | Electrónico | [Enlace](https://a.co/d/6dxQdtF) |
| Conectores XT90 | 1 | 23$ | Electrónico | [Enlace](https://a.co/d/9AgJER6) |
| Servomotores Injora 2065 7kg (3 Pcs) | 1 | 48$ | Mecánico | [Enlace](https://a.co/d/hfQbhOa) |
| Brazo de Servomotor Injora 25T | 1 | 9$ | Mecánico | [Enlace](https://a.co/d/9PtCohQ) |
| ESP32 | 1 | 10$ | Electrónico | [Enlace](https://www.amazon.com/ESP32-WROOM-32-Development-ESP-32S-Bluetooth-Arduino/dp/B084KWNMM4) |
| Step Down LM2596 | 1 | 6$ | Electrónico | [Enlace](https://robu.in/product/lm2596s-dc-dc-buck-converter-power-supply/) |
| Puente H L298N | 1 | 8$ | Electrónico | [Enlace](https://robu.in/product/l298-based-motor-driver-module-2a/)|
| PixyCam 2 | 1 | 69.99$ | Electrónico | [Enlace](https://a.co/d/i1WNaRs) |
| Motor Greartisan ZGA37IRG9I | 1 | 30$ | Mecánico |  |
| Giroscopio acelerometro Mpu6050 | 1 | 11$ | Electrónico | [Enlace](https://a.co/d/4NUOxoY) |
| Piñones de 5mm 1/8 13T y 14T | 1 | 12$ | Mecánico | [Enlace](https://a.co/d/0mrfcDG) |
| Piñones de 5mm 1/8 11T y 12T | 1 | 12$ | Mecánico | [Enlace](https://a.co/d/7t5SzPr) |
| Kit de conectores JST y DUPONT | 1 | 36$ | Electrónico | [Enlace](https://a.co/d/52pePQ9) |
| Kit de motor y variador de velocidad brushless, MBL32 y PURPLE VIPER 1721 1/18 | 1 | 60$ | Electrónico | [Enlace](https://a.co/d/6NRLPNy) |
| Tornillos M2 | 1 | 15$ | Mecánico | [Enlace](https://a.co/d/3gXOiNX) |
| Tuercas de Seguridad M2 | 1 | 10$ | Mecánico | [Enlace](https://a.co/d/1h8A71e) |
| Incertos roscados M2 | 1 | 9$ | Mecánico | [Enlace](https://a.co/d/eDrxGjF) |
| Tornillos M3 | 1 | 20$ | Mecánico | [Enlace](https://a.co/d/hlXXkAq) |
| Tuercas de Seguridad M3 | 1 | 7$ | Mecánico | [Enlace](https://a.co/d/2cXIxsE) |
| Incertos roscados M3 | 1 | 10$ | Mecánico | [Enlace](https://a.co/d/dOq3qJt) |
| Grasa de Litio Permatex | 1 | 11$ | Mecánico | [Enlace](https://a.co/d/6L1D8vk) |
| Cable trenzado 18 AWG | 1 | 11$ | Electrónico | [Enlace](https://a.co/d/7DPsW0) |
| Cable trenzado 22 AWG | 1 | 10$ | Electrónico | [Enlace](https://a.co/d/8ggmQSb) |
| Cable trenzado 26 AWG | 1 | 10$ | Electrónico | [Enlace](https://a.co/d/5TG2W9) |
| Filamento PETG para impresión 3D | 1 | 27$ | Electrónico | [Enlace](https://a.co/d/5QT5sDC) |
| Base de fijación de insertos roscados M2-M8 | 1 | 57$ | Electrónico | [Enlace](https://a.co/d/0QgemD) |
| Cautin Inalambrico de 100W | 1 | 95$ | Electrónico | [Enlace](https://a.co/d/7zn4xyp) |
| Filamento Pet-cf con Fibra de Carbono Bambu Lab 0.5kg 1.75mm | 1 | 60$ | Mecánico | [Enlace](https://articulo.mercadolibre.com.ve/MLV-769899404-filamento-pet-cf-con-fibra-de-carbono-bambu-lab-05kg-175mm-_JM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) |
| Kit de Actualización de Hotend Cerámico Ender V3 Se/Ke | 1 | 40$ | Mecánico | [Enlace](https://articulo.mercadolibre.com.ve/MLV-821933486-kit-de-actualizacion-de-hotend-ceramico-ender-3-v3-seke-_JM) |
| Secador de Filamento Space Pi | 1 | 85$ | Mecánico | [Enlace](https://articulo.mercadolibre.com.ve/MLV-768138623-creality-secador-de-filamento-space-pi-_JM) |
| Secador de Filamento Space Pi Plus | 1 | 140$ | Mecánico | [Enlace](https://articulo.mercadolibre.com.ve/MLV-821894608-creality-secador-de-filamento-space-pi-plus-_JM) |
| Ejes de transmisión escala 1/18 | 1 | 11$ | Mecánico | [Enlace](https://www.amazon.com/dp/B09P1QV29K) |
| Rolineras | 1 | 8.5$ | Mecánico | [Enlace](https://www.amazon.com/dp/B07XYPLPFL) |
| Grasa 8cc | 1 | 8$ | Mecánico | [Enlace](https://www.amazon.com/dp/B009PBVYPK) |
| Nudillos de cruce | 1 | 19$ | Mecánico | [Enlace](https://www.amazon.com/dp/B07D68MR25) |
| Rolineras | 1 | 10$ | Mecánico | [Enlace](https://www.amazon.com/dp/B0DXV2QMN4) |
| Ruedas de 40mm | 1 | 9$ | Mecánico | [Enlace](https://www.amazon.com/dp/B0DL8LJDH4) |
| Espaciadores y tornillos de nylon m3 | 1 | 17$ | Mecánico | [Enlace](https://www.amazon.com/dp/B0CBPGKDP4) |
| Diferenciales y ejes de transmisión escala 1/18 | 1 | 22$ | Mecánico | [Enlace](https://www.amazon.com/dp/B08GHC4D5M) |

---

> _¿Quieres contribuir o seguir nuestro avance? Síguenos en nuestras redes oficiales y revisa este repositorio para novedades y recursos._

---

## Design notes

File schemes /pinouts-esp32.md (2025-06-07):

(https://postimg.cc/6TqBgKN5)

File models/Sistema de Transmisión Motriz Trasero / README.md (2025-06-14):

Imagen de WhatsApp 2025-06-13 a las 22 14 21_c5e34e08

En nuestro sistema dedicado de transmisión trasera tenemos palieres y ejes de transmisión totalmente impresos en 3D los cuales dividimos en 5 partes

Inicialmente contamos con La copa del Diferencial; Gracias a este acople nos permite variar el grosor de los palieres y distancia entre la rueda y la transmisión,  asimismo más versatilidad en el rango de movimiento dado por el palier, robusta para una resistencia mecánica excepcional

Imagen de WhatsApp 2025-06-13 a las 22 23 46_622ee615

Seguido de La copa de diferencial está El Palier de transmisión trasera;
Este permite la potencia rotacional del diferencial directamente hacía las ruedas, lo cual permite un movimiento fluido y limpio de las mismas, reforzado para soportar la potencia rotacional y los movimientos de dirección y suspensión

Imagen de WhatsApp 2025-06-13 a las 22 29 32_efa944a1

Para transmitir el movimiento directamente a la rueda tenemos La Junta trasera, la cual esta conectada mecánicamente directamente a la rueda y a los Palieres de transmisión; Reposa sobre 2 cojinetes a medida (12x8x3.5) los cuales permiten transmitir la fuerza rotacional de manera eficiente y estable a las ruedas, con un diseño con un tornillo M2 interno para aportarle rigidez y estabilidad estructural

Imagen de WhatsApp 2025-06-13 a las 22 35 18_7b2dfa9f

Acoplado directamente a la Junta Trasera, nos encontramos con el Ring de encaje hexagonal, el cual es el encargado de transformala potencia rotacional de los diferenciales, Palieres y Juntas en movimiento físico del robot de manera eficiente y fluida

Imagen de WhatsApp 2025-06-13 a las 22 38 02_b38a46af

Por último nos encontramos con el Pivote trasero,en el cual reposa todo el sistema de cojinetes los cuales le dan libertad de movimiento a las Ruedas, Palieres y Juntas, este esta fijo atornillado al Chasis para proporcionarle estabilidad total al sistema

Imagen de WhatsApp 2025-06-13 a las 22 40 45_d5034267

Como diseño Extra quisimos agregar un Alineador de transmisión trasera, fijo al chasis, este nos da un rango de alineación de las ruedas traseras para poder aportar una transmisión estable y precisa

Imagen de WhatsApp 2025-06-13 a las 22 43 35_d7d401e9

Imagen de WhatsApp 2025-06-13 a las 22 44 36_969d7c80

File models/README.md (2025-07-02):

# Modelos del Robot – Carpeta `models`

¡Bienvenido a la carpeta de modelos!
Aquí encontrarás todos los archivos y documentación relacionados con los componentes físicos y mecánicos del robot, especialmente aquellos diseñados y listos para impresión 3D.

---

## Estructura de Carpetas y Descripción

A continuación se detallan las subcarpetas principales que conforman este directorio, junto a una breve descripción de su propósito:

---

### 1. **Bases y Acoples de Sensores y Cámara**
- **Descripción:**  
  Aquí se encuentran los modelos 3D de las bases y acoples para la fijación de sensores y la cámara del robot. 

### 2. **Cajas de Diferencial y Chasis Principal**
- **Descripción:**  
  Contiene los archivos de diseño para la estructura principal del robot, incluyendo el chasis central y las cajas del diferencial. Estos modelos brindan el soporte estructural necesario y alojan los mecanismos internos de transmisión y control.

---

### 3. **Impresión y Diseño 3D**
- **Descripción:**  
  Reúne los archivos fuente (STL, STEP, etc.) y documentación relacionada con el proceso de diseño e impresión 3D. Aquí se incluyen guías para la fabricación, recomendaciones de materiales, y configuraciones de impresión.

---

### 4. **Sistema de Movimiento Libre y Dirección Delantera**
- **Descripción:**  
  Incluye los modelos para los sistemas delanteros de dirección y movimiento libre. Aquí se encuentran los componentes que permiten al robot girar y maniobrar con precisión.
---

### 5. **Sistema de Transmisión Motriz Trasero**
- **Descripción:**  
  Contiene los diseños de la transmisión motriz trasera, tales como soportes de motores, engranajes, ejes y acoples. Estos elementos son fundamentales para el desplazamiento eficiente y la entrega de potencia a las ruedas traseras del robot.

---

> [!NOTE]
>  ¿Cómo usar estos modelos?
> 1. **Revisa el README específico de cada subcarpeta** para detalles técnicos y notas de montaje.
> 2. **Descarga los archivos de la pieza que necesites** y prepáralos según las recomendaciones de impresión.
> 3. **Consulta las guías y diagramas** para el ensamblaje correcto y evitar errores durante el armado del robot.

---

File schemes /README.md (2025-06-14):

# README de la carpeta de esquemas

aquí se encuentran todos los esquemas utilizados a lo largo del GitHub, en formato markdown y incluyendo algunas tablas de información tipo esquema de los componentes del robot

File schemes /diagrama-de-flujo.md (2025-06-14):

// Diagrama de Flujo Alternativo, posee la misma lógica pero en formato diferente, el Diagrama Oficial se encuentra en README.md

(https://postimg.cc/YhFJbXzr)

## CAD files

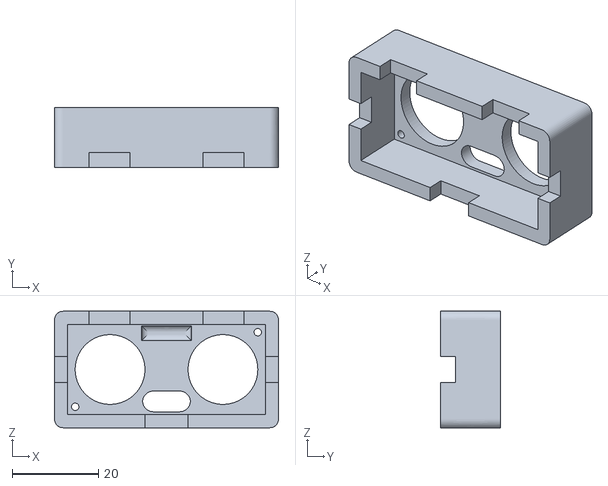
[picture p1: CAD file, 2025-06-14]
models/Bases y Acoples de Sensores y Cámara/base de acople de ultrasonicos .stl
52.0 x 14.0 x 27.1

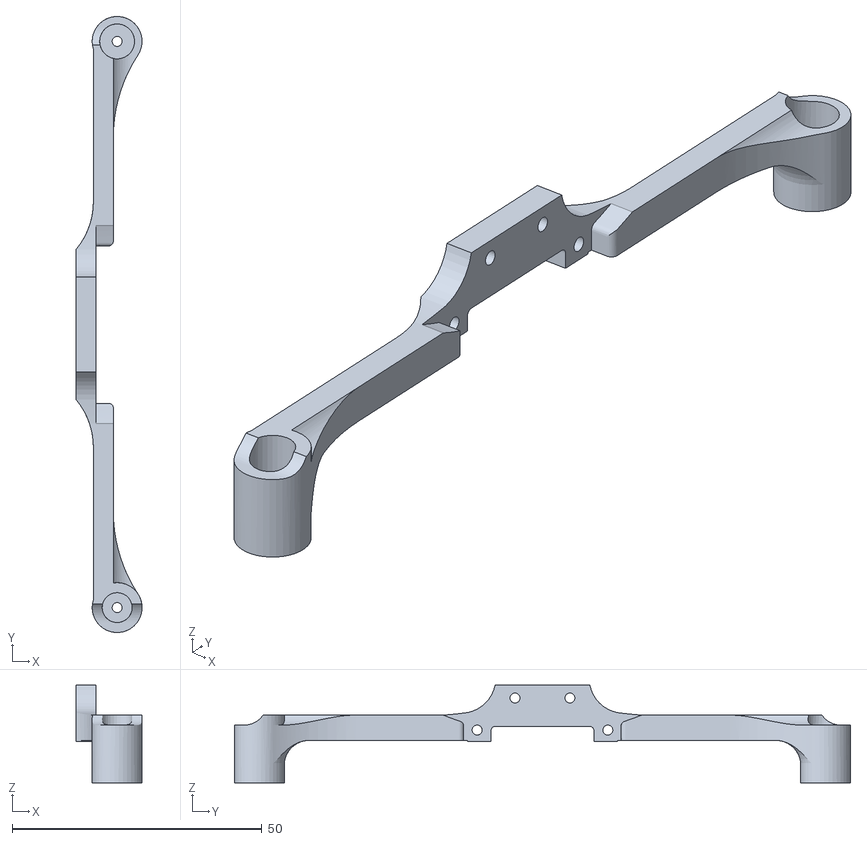
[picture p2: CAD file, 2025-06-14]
models/Sistema de Movimiento libre y Dirección Delantera/Varilla de refuerzo de tren delantero.stl
13.3 x 123.4 x 19.6

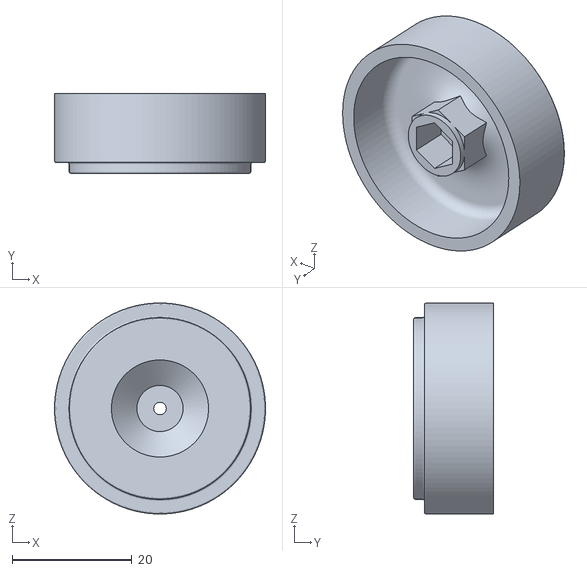
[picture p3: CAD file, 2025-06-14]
models/Sistema de Transmisión Motriz Trasero /Ring de encaje hexagonal.stl
35.2 x 13.3 x 35.2

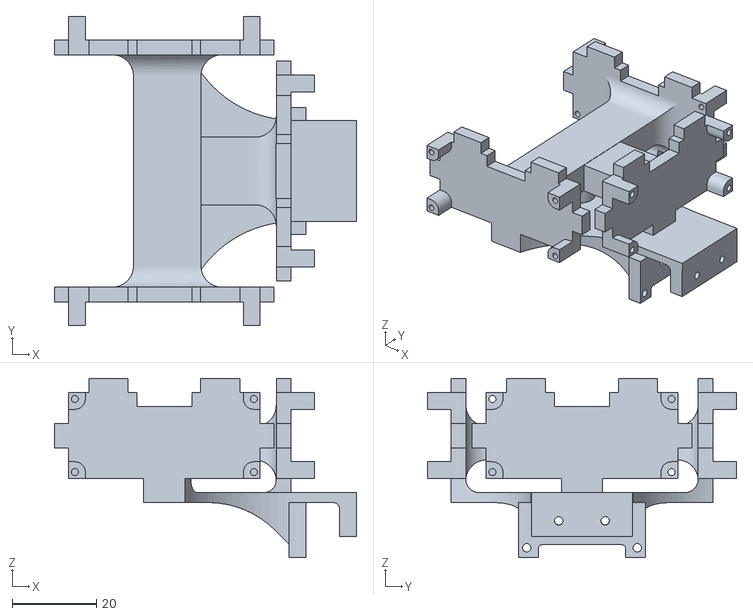
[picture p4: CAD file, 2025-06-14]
models/Bases y Acoples de Sensores y Cámara/base de ultrasonicos y pixy principal.stl
71.5 x 73.2 x 42.4

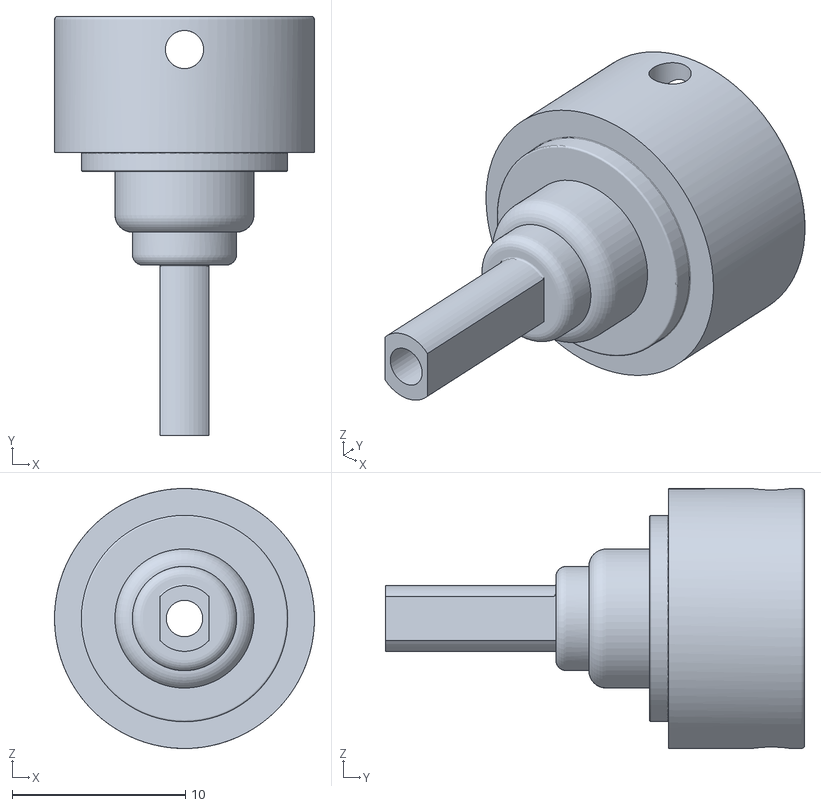
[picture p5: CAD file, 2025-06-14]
models/Sistema de Movimiento libre y Dirección Delantera/Junta delantera.stl
15.0 x 24.2 x 15.0

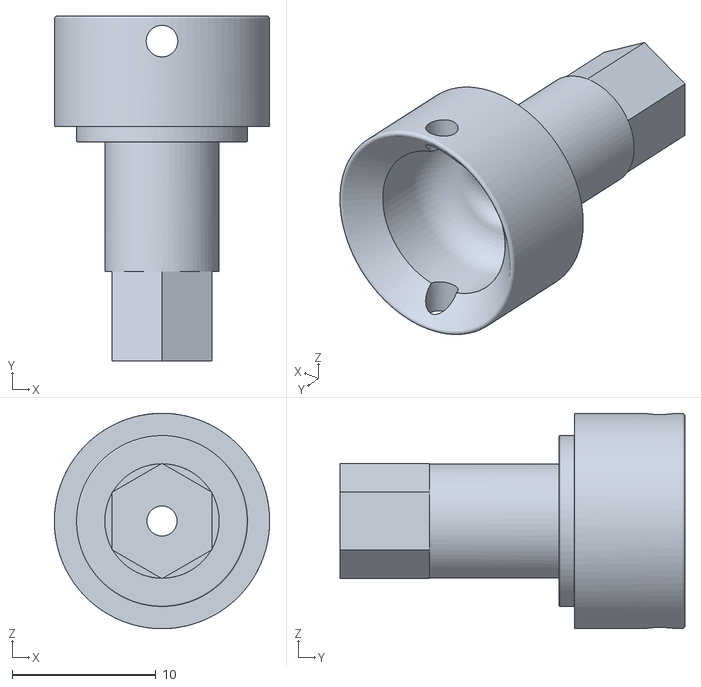
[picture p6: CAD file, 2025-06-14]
models/Sistema de Transmisión Motriz Trasero / Junta trasera.stl
15.0 x 24.0 x 15.0

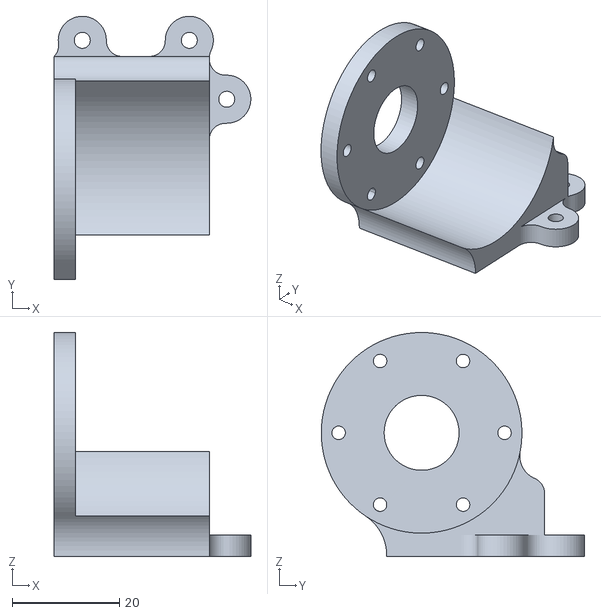
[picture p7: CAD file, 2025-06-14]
models/Bases y Acoples de Sensores y Cámara/base de motor.stl
36.7 x 49.2 x 41.9

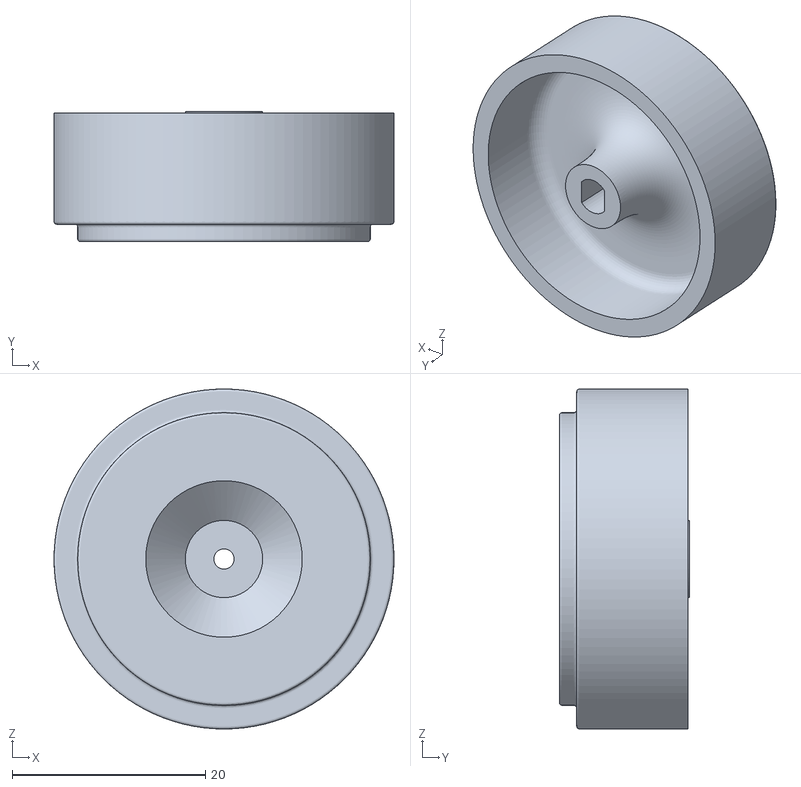
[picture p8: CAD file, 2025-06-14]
models/Sistema de Movimiento libre y Dirección Delantera/rueda de encaje ovalado semirecto.stl
35.2 x 13.5 x 35.2

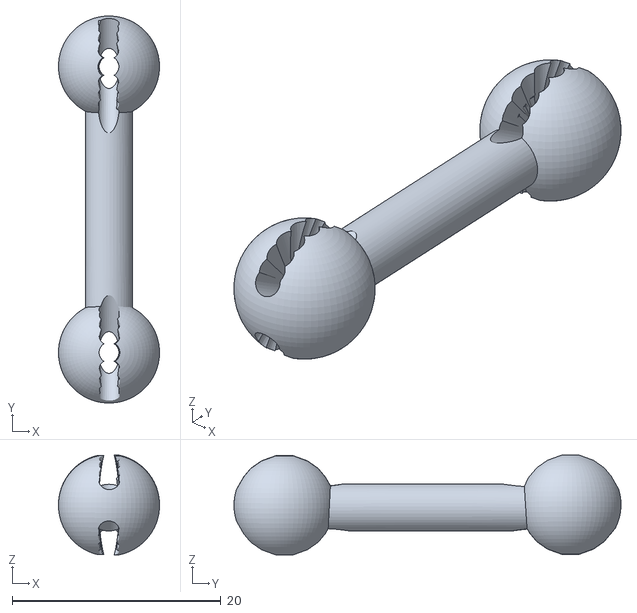
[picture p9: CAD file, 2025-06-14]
models/Sistema de Transmisión Motriz Trasero /Palier de transmisión trasera.stl
9.69 x 37.1 x 9.57

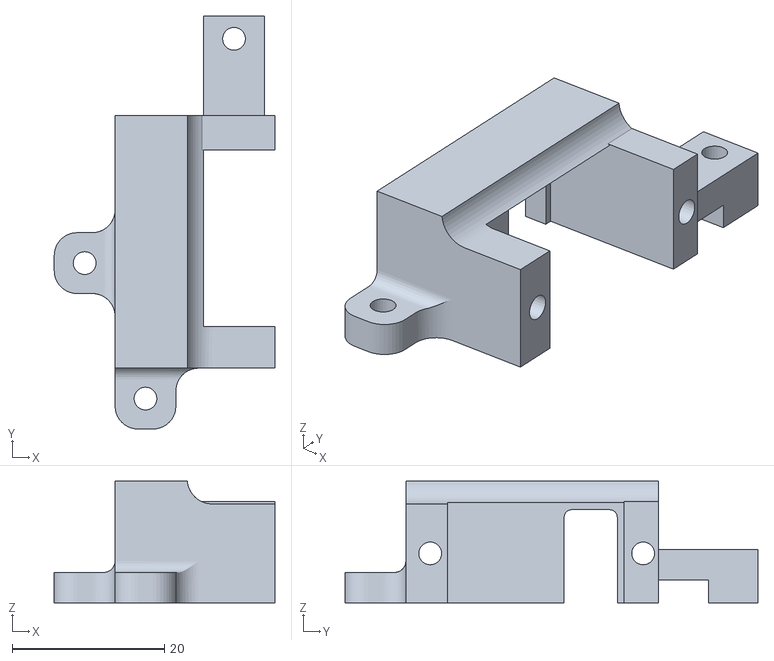
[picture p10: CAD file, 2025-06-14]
models/Bases y Acoples de Sensores y Cámara/bracket de servo.stl
29.0 x 54.3 x 16.0

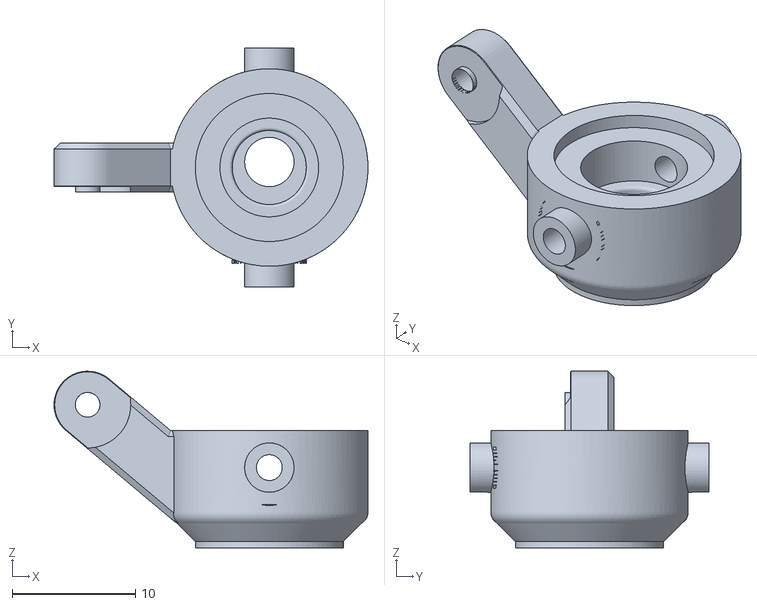
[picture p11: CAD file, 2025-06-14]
models/Sistema de Movimiento libre y Dirección Delantera/Pivote frontal.stl
25.5 x 19.4 x 14.3

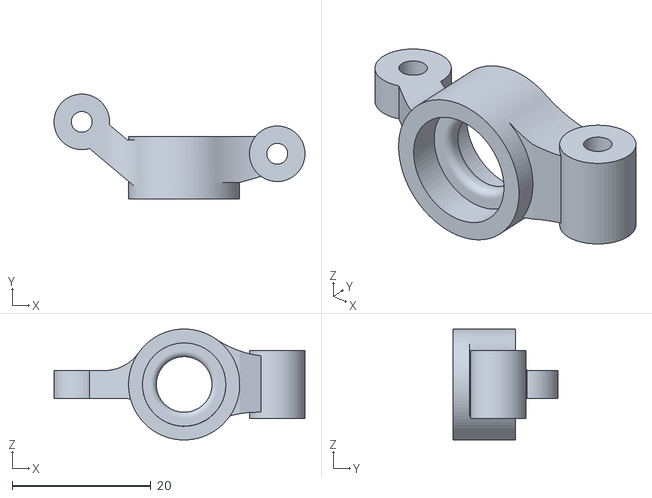
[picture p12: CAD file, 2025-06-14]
models/Sistema de Transmisión Motriz Trasero /Pivote trasero.stl
36.1 x 15.1 x 16.0

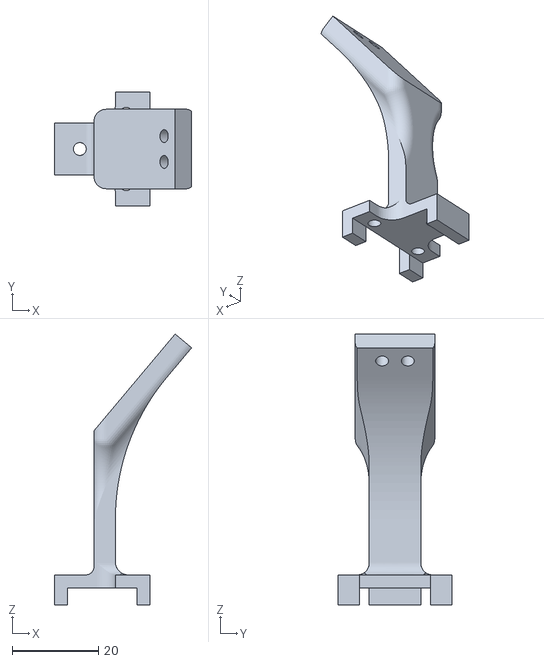
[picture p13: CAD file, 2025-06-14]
models/Bases y Acoples de Sensores y Cámara/base de pixy .stl
31.9 x 26.4 x 63.0

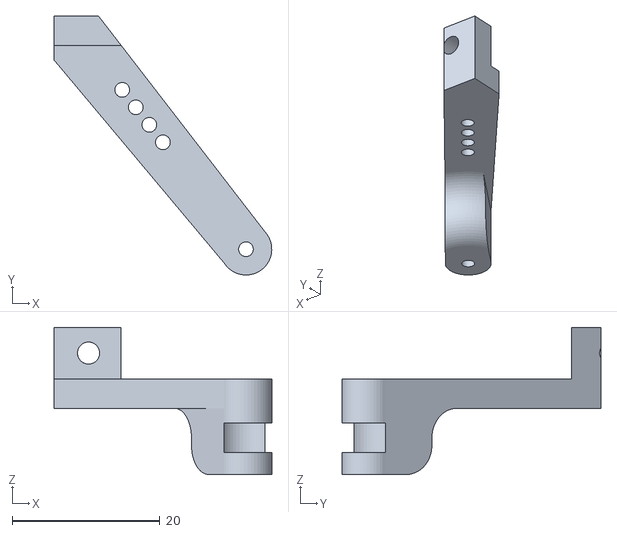
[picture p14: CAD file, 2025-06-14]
models/Sistema de Movimiento libre y Dirección Delantera/palier de dirección derecho.stl
29.5 x 35.1 x 20.0

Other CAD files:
models/Sistema de Transmisión Motriz Trasero /copa de diferencial.stl
models/Sistema de Movimiento libre y Dirección Delantera/chasis principal.stl
models/Sistema de Transmisión Motriz Trasero / Alineador de transmisión trasera.stl
models/Sistema de Movimiento libre y Dirección Delantera/caja de diferencial superior.stl
models/Sistema de Movimiento libre y Dirección Delantera/caja de diferencial inferior .stl
models/Sistema de Movimiento libre y Dirección Delantera/prisionero de rolinera de transmisión del motor al eje.stl

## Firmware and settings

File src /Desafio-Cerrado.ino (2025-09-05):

#include <Wire.h>
#include <ESP32Servo.h>
#include <SPI.h>
#include <Pixy2SPI_SS.h>
#include <NewPing.h>

// Pines y canales
#define IN1 16
#define IN2 17
#define MOTOR_PWM_CHANNEL 6
#define MOTOR_PWM_PIN IN1
#define PIN_SERVO 2
#define PIN_BOTON 15

#define USTLEFT 14
#define USELEFT 27
#define USTRIGHT 26
#define USERIGHT 25
#define USTFRONT 13
#define USEFRONT 12

#define MAX_DISTANCE 357
#define PWM_FREQUENCY 5000
#define PWM_RESOLUTION 8

NewPing sensorFront(USTFRONT, USEFRONT, MAX_DISTANCE);
NewPing sensorIzq(USTLEFT, USELEFT, MAX_DISTANCE);
NewPing sensorDer(USTRIGHT, USERIGHT, MAX_DISTANCE);

Pixy2SPI_SS pixy;
Servo myservo;

// Velocidades
int velocidadNormal = 150;
int velocidadReversa = 100;
int velocidadGiro = 150;

// Parámetros de control
const int ANGULO_CENTRO = 98;
const int ANGULO_MAX = 128;    // Máximo giro a la DERECHA (98 + 30)
const int ANGULO_MIN = 68;     // Máximo giro a la IZQUIERDA (98 - 30)

// Parámetros de esquiva (ajustables)
const int ANGULO_ESQUIVA_PRIMARIO = 25;   // Grados de giro para la primera parte de la esquiva
const int ANGULO_ESQUIVA_SECUNDARIO = 20; // Grados de giro para la segunda parte de la esquiva
const unsigned long TIEMPO_ESQUIVA_PRIMARIA = 730;   // Tiempo primera parte de la esquiva
const unsigned long TIEMPO_RECTA_ENTRE_GIROS = 100;  // Tiempo yendo recto entre giros
const unsigned long TIEMPO_ESQUIVA_SECUNDARIA = 650; // Tiempo segunda parte de la esquiva

// Tiempos de maniobras (en milisegundos) - DIFERENTES PARA CADA BLOQUE
const unsigned long TIEMPO_ESQUIVA_VERDE = TIEMPO_ESQUIVA_PRIMARIA + TIEMPO_RECTA_ENTRE_GIROS + TIEMPO_ESQUIVA_SECUNDARIA;
const unsigned long TIEMPO_ESQUIVA_ROJO = TIEMPO_ESQUIVA_PRIMARIA + TIEMPO_RECTA_ENTRE_GIROS + TIEMPO_ESQUIVA_SECUNDARIA;

// Tiempos POST-ESQUIVA DIFERENTES para cada bloque
const unsigned long TIEMPO_POST_ESQUIVA_VERDE = 100;   // Tiempo para avanzar después de la esquiva verde
const unsigned long TIEMPO_POST_ESQUIVA_ROJO = 150;    // Tiempo para avanzar después de la esquiva rojo

// Tiempos de GIRO DIFERENTES para cada bloque
const unsigned long TIEMPO_GIRO_DERECHA_VERDE = 850;   // Tiempo para girar a la derecha después de esquiva verde
const unsigned long TIEMPO_GIRO_IZQUIERDA_VERDE = 630; // Tiempo para girar a la izquierda después de esquiva verde
const unsigned long TIEMPO_GIRO_IZQUIERDA_ROJO = 690;  // Tiempo para girar a la izquierda después de esquiva rojo
const unsigned long TIEMPO_GIRO_DERECHA_ROJO = 500;    // Tiempo para girar a la derecha después de esquiva rojo

const unsigned long TIEMPO_RETROCESO = 1000;
const unsigned long TIEMPO_DETENCION = 3000;
const unsigned long TIEMPO_RETROCESO_FINAL = 3000;

// Umbrales de detección de Pixy INDEPENDIENTES para cada bloque
const int UMBRAL_TAMANO_BLOQUE_VERDE = 2500;  // Umbral específico para bloque verde
const int UMBRAL_TAMANO_BLOQUE_ROJO = 100;   // Umbral específico para bloque rojo
const int OBSTACULO_FRONTAL = 26;

// Estados del robot
enum Estado {
  DETENIDO,
  AVANZAR,
  ESQUIVAR_VERDE_IZQ,
  ESQUIVAR_ROJO_DER,
  POST_ESQUIVA_VERDE,  // Secuencia después de esquivar verde
  POST_ESQUIVA_ROJO,   // Secuencia después de esquivar rojo
  GIRO_SERVO,
  RETROCEDER_CON_GIRO,
  RETROCEDER_FINAL,
  REAJUSTAR_POSICION
};

Estado estadoActual = DETENIDO;
bool bloqueVerdeDetectado = false;
bool bloqueRojoDetectado = false;
bool bloqueVerdeCercano = false;
bool bloqueRojoCercano = false;
int posicionBloqueX = 0;
int ladoMasLibre = 0;

// Variables para el control de movimiento por tiempo
unsigned long tiempoInicioManiobra = 0;
unsigned long tiempoFaseActual = 0;

void setup() {
  Serial.begin(115200);
  
  // Configurar pines de motor
  pinMode(IN1, OUTPUT);
  pinMode(IN2, OUTPUT);
  ledcSetup(MOTOR_PWM_CHANNEL, PWM_FREQUENCY, PWM_RESOLUTION);
  ledcAttachPin(MOTOR_PWM_PIN, MOTOR_PWM_CHANNEL);
  
  // Configurar servo
  myservo.attach(PIN_SERVO);
  myservo.write(ANGULO_CENTRO);
  
  // Configurar botón
  pinMode(PIN_BOTON, INPUT_PULLUP);
  
  // Inicializar Pixy
  pixy.init();
  
  // Encender luces de la Pixy
  pixy.setLamp(1, 1);
  
  Serial.println("Robot inicializado. Presione el botón para comenzar.");
}

void loop() {
  // Leer estado del botón
  if (digitalRead(PIN_BOTON) == LOW && estadoActual == DETENIDO) {
    estadoActual = AVANZAR;
    delay(500);
    Serial.println("Iniciando movimiento");
  }
  
  // Leer sensores ultrasónicos
  int distanciaFrontal = sensorFront.ping_cm();
  int distanciaIzquierda = sensorIzq.ping_cm();
  int distanciaDerecha = sensorDer.ping_cm();
  
  // Leer datos de Pixy (pero no detener la maniobra if ya comenzó)
  if (estadoActual != ESQUIVAR_VERDE_IZQ && estadoActual != ESQUIVAR_ROJO_DER && 
      estadoActual != POST_ESQUIVA_VERDE && estadoActual != POST_ESQUIVA_ROJO) {
    leerPixy();
  }
  
  // Mostrar información de depuración
  if (millis() % 1000 < 50) {
    Serial.print("Estado: ");
    Serial.print(estadoActual);
    Serial.print(" | Frontal: ");
    Serial.print(distanciaFrontal);
    Serial.print("cm | Izq: ");
    Serial.print(distanciaIzquierda);
    Serial.print("cm | Der: ");
    Serial.print(distanciaDerecha);
    Serial.print("cm | Verde: ");
    Serial.print(bloqueVerdeDetectado);
    Serial.print(" | Rojo: ");
    Serial.print(bloqueRojoDetectado);
    Serial.print(" | VerdeCerca: ");
    Serial.print(bloqueVerdeCercano);
    Serial.print(" | RojoCerca: ");
    Serial.print(bloqueRojoCercano);
    Serial.print(" | PosX: ");
    Serial.print(posicionBloqueX);
    Serial.print(" | Lado libre: ");
    Serial.println(ladoMasLibre);
  }
  
  // Máquina de estados del robot
  switch (estadoActual) {
    case DETENIDO:
      detenerRobot();
      break;
      
    case AVANZAR:
      avanzar();
      myservo.write(ANGULO_CENTRO);
      
      // Verificar obstáculos y tomar decisiones
      if (distanciaFrontal > 0 && distanciaFrontal < OBSTACULO_FRONTAL) {
        if (!bloqueVerdeDetectado && !bloqueRojoDetectado) {
          if (distanciaIzquierda > distanciaDerecha + 5) {
            ladoMasLibre = 1;
          } else if (distanciaDerecha > distanciaIzquierda + 5) {
            ladoMasLibre = -1;
          } 
          
          estadoActual = GIRO_SERVO;
          tiempoInicioManiobra = millis();
          Serial.println("Obstáculo frontal detectado, girando servo");
        }
      }
      
      // Comportamiento según color detectado
      if (bloqueVerdeDetectado && bloqueVerdeCercano) {
        if (posicionBloqueX == 1) {
          Serial.println("Verde detectado a la derecha, sigo recto");
        } else if (posicionBloqueX == -1) {
          estadoActual = ESQUIVAR_VERDE_IZQ;
          tiempoInicioManiobra = millis();
          Serial.println("Verde detectado a la izquierda, iniciando esquiva");
        }
      } else if (bloqueRojoDetectado && bloqueRojoCercano) {
        if (posicionBloqueX == -1) {
          Serial.println("Rojo detectado a la izquierda, sigo recto");
        } else if (posicionBloqueX == 1) {
          estadoActual = ESQUIVAR_ROJO_DER;
          tiempoInicioManiobra = millis();
          Serial.println("Rojo detectado a la derecha, iniciando esquiva");
        }
      }
      break;
      
    case ESQUIVAR_VERDE_IZQ:
      // Esquiva para bloque verde a la izquierda
      tiempoFaseActual = millis() - tiempoInicioManiobra;
      
      if (tiempoFaseActual < TIEMPO_ESQUIVA_PRIMARIA) {
        // Primera fase: girar a la derecha para esquivar
        myservo.write(ANGULO_CENTRO + ANGULO_ESQUIVA_PRIMARIO);
        avanzar();
        Serial.println("Fase 1: Esquivando a la derecha");
      } else if (tiempoFaseActual < TIEMPO_ESQUIVA_PRIMARIA + TIEMPO_RECTA_ENTRE_GIROS) {
        // Segunda fase: centrar y avanzar recto
        myservo.write(ANGULO_CENTRO);
        avanzar();
        Serial.println("Fase 2: Avanzando recto");
      } else if (tiempoFaseActual < TIEMPO_ESQUIVA_VERDE) {
        // Tercera fase: girar a la izquierda para re-centrar
        myservo.write(ANGULO_CENTRO - ANGULO_ESQUIVA_SECUNDARIO);
        avanzar();
        Serial.println("Fase 3: Re-centrando a la izquierda");
      } else {
        // Finalizar maniobra e iniciar secuencia post-esquiva
        estadoActual = POST_ESQUIVA_VERDE;
        tiempoInicioManiobra = millis();
        Serial.println("Esquiva verde completada, iniciando secuencia post-esquiva");
      }
      break;
      
    case POST_ESQUIVA_VERDE:
      // Secuencia adicional después de esquivar el bloque verde (TIEMPOS ESPECÍFICOS PARA VERDE)
      tiempoFaseActual = millis() - tiempoInicioManiobra;
      
      if (tiempoFaseActual < TIEMPO_POST_ESQUIVA_VERDE) {
        // Avanzar recto (tiempo específico para verde)
        myservo.write(ANGULO_CENTRO);
        avanzar();
        Serial.println("Post-esquiva verde: Avanzando recto");
      } else if (tiempoFaseActual < TIEMPO_POST_ESQUIVA_VERDE + TIEMPO_GIRO_DERECHA_VERDE) {
        // Girar a la derecha (tiempo específico para verde)
        myservo.write(ANGULO_CENTRO - ANGULO_ESQUIVA_PRIMARIO);
        avanzar();
        Serial.println("Post-esquiva verde: Girando a la derecha");
      } else if (tiempoFaseActual < TIEMPO_POST_ESQUIVA_VERDE + TIEMPO_GIRO_DERECHA_VERDE + TIEMPO_RECTA_ENTRE_GIROS) {
        // Centrar el servo
        myservo.write(ANGULO_CENTRO);
        avanzar();
        Serial.println("Post-esquiva verde: Centrando servo");
      } else if (tiempoFaseActual < TIEMPO_POST_ESQUIVA_VERDE + TIEMPO_GIRO_DERECHA_VERDE + TIEMPO_RECTA_ENTRE_GIROS + TIEMPO_GIRO_IZQUIERDA_VERDE) {
        // Girar a la izquierda (tiempo específico para verde)
        myservo.write(ANGULO_CENTRO + ANGULO_ESQUIVA_PRIMARIO);
        avanzar();
        Serial.println("Post-esquiva verde: Girando a la izquierda");
      } else {
        // Finalizar secuencia y volver a avanzar normalmente
        myservo.write(ANGULO_CENTRO);
        estadoActual = AVANZAR;
        Serial.println("Secuencia post-esquiva verde completada, avanzando normalmente");
      }
      break;
      
    case ESQUIVAR_ROJO_DER:
      // Esquiva para bloque rojo a la derecha
      tiempoFaseActual = millis() - tiempoInicioManiobra;
      
      if (tiempoFaseActual < TIEMPO_ESQUIVA_PRIMARIA) {
        // Primera fase: girar a la izquierda para esquivar
        myservo.write(ANGULO_CENTRO - ANGULO_ESQUIVA_PRIMARIO);
        avanzar();
        Serial.println("Fase 1: Esquivando a la izquierda");
      } else if (tiempoFaseActual < TIEMPO_ESQUIVA_PRIMARIA + TIEMPO_RECTA_ENTRE_GIROS) {
        // Segunda fase: centrar y avanzar recto
        myservo.write(ANGULO_CENTRO);
        avanzar();
        Serial.println("Fase 2: Avanzando recto");
      } else if (tiempoFaseActual < TIEMPO_ESQUIVA_ROJO) {
        // Tercera fase: girar a la derecha para re-centrar
        myservo.write(ANGULO_CENTRO + ANGULO_ESQUIVA_SECUNDARIO);
        avanzar();
        Serial.println("Fase 3: Re-centrando a la derecha");
      } else {
        // Finalizar maniobra e iniciar secuencia post-esquiva para rojo
        estadoActual = POST_ESQUIVA_ROJO;
        tiempoInicioManiobra = millis();
        Serial.println("Esquiva rojo completada, iniciando secuencia post-esquiva");
      }
      break;
      
    case POST_ESQUIVA_ROJO:
      // Secuencia adicional después de esquivar el bloque rojo (TIEMPOS ESPECÍFICOS PARA ROJO)
      tiempoFaseActual = millis() - tiempoInicioManiobra;
      
      if (tiempoFaseActual < TIEMPO_POST_ESQUIVA_ROJO) {
        // Avanzar recto (tiempo específico para rojo)
        myservo.write(ANGULO_CENTRO);
        avanzar();
        Serial.println("Post-esquiva rojo: Avanzando recto");
      } else if (tiempoFaseActual < TIEMPO_POST_ESQUIVA_ROJO + TIEMPO_GIRO_IZQUIERDA_ROJO) {
        // Girar a la izquierda (tiempo específico para rojo)
        myservo.write(ANGULO_CENTRO + ANGULO_ESQUIVA_PRIMARIO);
        avanzar();
        Serial.println("Post-esquiva rojo: Girando a la izquierda");
      } else if (tiempoFaseActual < TIEMPO_POST_ESQUIVA_ROJO + TIEMPO_GIRO_IZQUIERDA_ROJO + TIEMPO_RECTA_ENTRE_GIROS) {
        // Centrar el servo
        myservo.write(ANGULO_CENTRO);
        avanzar();
        Serial.println("Post-esquiva rojo: Centrando servo");
      } else if (tiempoFaseActual < TIEMPO_POST_ESQUIVA_ROJO + TIEMPO_GIRO_IZQUIERDA_ROJO + TIEMPO_RECTA_ENTRE_GIROS + TIEMPO_GIRO_DERECHA_ROJO) {
        // Girar a la derecha (tiempo específico para rojo)
        myservo.write(ANGULO_CENTRO - ANGULO_ESQUIVA_PRIMARIO);
        avanzar();
        Serial.println("Post-esquiva rojo: Girando a la derecha");
      } else {
        // Finalizar secuencia y volver a avanzar normalmente
        myservo.write(ANGULO_CENTRO);
        estadoActual = AVANZAR;
        Serial.println("Secuencia post-esquiva rojo completada, avanzando normalmente");
      }
      break;
      
    case GIRO_SERVO:
      if (ladoMasLibre == -1) {
        myservo.write(ANGULO_MAX); // Girar a la DERECHA (contrario a izquierda libre)
        Serial.println("Servo girado a derecha (contrario a izquierda libre)");
      } else {
        myservo.write(ANGULO_MIN); // Girar a la IZQUIERDA (contrario a derecha libre)
        Serial.println("Servo girado a izquierda (contrario a derecha libre)");
      }
      
      estadoActual = RETROCEDER_CON_GIRO;
      tiempoInicioManiobra = millis();
      break;
      
    case RETROCEDER_CON_GIRO:
      tiempoFaseActual = millis() - tiempoInicioManiobra;
      
      if (tiempoFaseActual < TIEMPO_RETROCESO) {
        retroceder();
        Serial.println("Retrocediendo con servo girado");
      } else {
        myservo.write(ANGULO_CENTRO);
        estadoActual = RETROCEDER_FINAL;
        tiempoInicioManiobra = millis();
        Serial.println("Centrando servo y retrocediendo más");
      }
      break;
      
    case RETROCEDER_FINAL:
      tiempoFaseActual = millis() - tiempoInicioManiobra;
      
      if (tiempoFaseActual < TIEMPO_RETROCESO_FINAL) {
        retroceder();
        Serial.println("Retrocediendo final hacia la pared");
      } else {
        estadoActual = AVANZAR;
        Serial.println("Retroceso finalizado, avanzando");
      }
      break;
      
    case REAJUSTAR_POSICION:
      estadoActual = AVANZAR;
      break;
  }
  
  delay(50);
}

void leerPixy() {
  static unsigned long ultimaLectura = 0;
  
  if (millis() - ultimaLectura > 100) {
    ultimaLectura = millis();
    
    pixy.ccc.getBlocks();
    
    bloqueVerdeDetectado = false;
    bloqueRojoDetectado = false;
    bloqueVerdeCercano = false;
    bloqueRojoCercano = false;
    posicionBloqueX = 0;
    
    if (pixy.ccc.numBlocks) {
      for (int i = 0; i < pixy.ccc.numBlocks; i++) {
        if (pixy.ccc.blocks[i].m_signature == 1) {
          bloqueVerdeDetectado = true;
          if (pixy.ccc.blocks[i].m_x < pixy.frameWidth / 2) {
            posicionBloqueX = -1;
          } else {
            posicionBloqueX = 1;
          }
          // Umbral específico para verde
          if (pixy.ccc.blocks[i].m_width * pixy.ccc.blocks[i].m_height > UMBRAL_TAMANO_BLOQUE_VERDE) {
            bloqueVerdeCercano = true;
          }
          break;
        }
        else if (pixy.ccc.blocks[i].m_signature == 2) {
          bloqueRojoDetectado = true;
          if (pixy.ccc.blocks[i].m_x < pixy.frameWidth / 2) {
            posicionBloqueX = -1;
          } else {
            posicionBloqueX = 1;
          }
          // Umbral específico para rojo
          if (pixy.ccc.blocks[i].m_width * pixy.ccc.blocks[i].m_height > UMBRAL_TAMANO_BLOQUE_ROJO) {
            bloqueRojoCercano = true;
          }
          break;
        }
      }
    }
  }
}

void avanzar() {
  digitalWrite(IN1, HIGH);
  digitalWrite(IN2, LOW);
  ledcWrite(MOTOR_PWM_CHANNEL, velocidadNormal);
}

void retroceder() {
  digitalWrite(IN1, LOW);
  digitalWrite(IN2, HIGH);
  ledcWrite(MOTOR_PWM_CHANNEL, velocidadReversa);
}

void detenerRobot() {
  digitalWrite(IN1, LOW);
  digitalWrite(IN2, LOW);
  ledcWrite(MOTOR_PWM_CHANNEL, 0);
}

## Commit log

2025-05-19 Primera versión de ValRepo
2025-05-26 Actualizar README.md
    cambio de micro
2025-05-26 Actualizar README.md (#1)
    cambio de código heimdall
2025-05-28 Actualizar README.md corrección de errores de formato
2025-06-06 Rename u to chassis.stl
    [chassis.stl]
2025-06-07 Create wiring-diagram
2025-06-07 Rename chassis.stl to chasis.stl
    [chasis.stl]
2025-06-07 Update diagrama-de-flujo
2025-06-07 Actualizar pinouts-esp32.md
2025-06-14 Update README.md
    flowchart
2025-06-14 Crear diagrama-de-conexiones.md
2025-06-14 Crear Sistema de Transmisión Motriz Trasero / README.md
2025-06-14 Crear Cajas de Diferencial y Chasis Principal / README.md
2025-06-14 Crear Bases y Acoples de Sensores y Cámara / README.md
2025-06-14 Rename Alineador de transmisión trasera.stl to Alineador de transmisión trasera.stl
    [Alineador de transmisión trasera.stl]
2025-06-14 Rename Junta trasera.stl to Junta trasera.stl
    [Junta trasera.stl]
2025-06-14 Rename Palier de transmisión trasera.stl to Palier de transmisión trasera.stl
    [Palier de transmisión trasera.stl]
2025-06-14 Rename Pivote trasero.stl to Pivote trasero.stl
    [Pivote trasero.stl]
2025-06-14 Rename Ring de encaje hexagonal.stl to Ring de encaje hexagonal.stl
    [Ring de encaje hexagonal.stl]
2025-06-14 Rename copa de diferencial.stl to copa de diferencial.stl
    [copa de diferencial.stl]
2025-06-14 Actualizar diagrama-de-flujo.md
2025-07-02 Crear fuerzas-mecánica-flowchart.md
2025-07-02 Crear desafio-abierto-flowchart.md
2025-07-02 Crear desafio-cerrado-flowchart.md
2025-07-02 Actualizar desafio-abierto-flowchart.md
2025-07-02 Actualizar desafio-cerrado-flowchart.md
2025-07-02 Actualizar fuerzas-mecánica-flowchart.md
